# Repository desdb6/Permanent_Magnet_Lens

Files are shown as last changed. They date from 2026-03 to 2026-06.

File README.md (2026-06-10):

# Permanent Magnet Electron Lens
**A compact and open-source permanent magnet electron lens: from simulation to realisation**

*Bachelor's thesis — Des De Borger, supervised by Prof. Dr. Johan Verbeeck*  
*EMAT, Department of Physics, University of Antwerp, 2025–2026*

---

## Overview

This repository contains the simulation toolbox and CAD files developed for the design, optimisation, and experimental validation of a miniature electron lens based on a permanent Nd₂Fe₁₄B ring magnet with two ferromagnetic AISI 1018 pole pieces. The lens was tested in a 30 kV Tescan MIRA scanning electron microscope, producing magnified images with a magnification of ×6.

The goal is to contribute to the development of compact, energy-efficient, and open-source electron microscopes with a significantly lower cost threshold than conventional solenoid-based systems.

---

## Repository structure

```
├── sim.py                   # Full simulation toolbox (Lens class + helper functions)
├── NdFeB_BH_curve.csv       # BH-curve data for grade N35 Nd₂Fe₁₄B magnet
├── 3D_Models/
│   ├── polepiece.FCStd      # FreeCAD parametric model of the pole pieces
│   ├── polepiece.step       # STEP file for CNC manufacturing
│   ├── lens_holder.blend    # Blender model of the 3D-printed lens holder
│   ├── grid_holder.blend    # Blender model of the 3D-printed grid holder
│   └── aperture.blend       # Blender model of the 3D-printed aperture
└── README.md
```

---

## Physics background

The lens consists of a homogeneously magnetised Nd₂Fe₁₄B ring magnet combined with two axially symmetric pole pieces. The pole pieces concentrate the magnetic field into the air gap at the centre of the lens, producing a strongly peaked, cylindrically symmetric field B(z) along the optical axis.

The field is modelled analytically by treating the pole-piece surfaces bordering the air gap as homogeneously charged magnetic surface charge distributions (annuli with charge density ±σ_M). The on-axis field is:

$$B(z) = \frac{B_m A_m}{A_g} \cdot \frac{1}{2}\left[\left(z+\frac{d}{2}\right)\left(\frac{1}{\sqrt{(z+d/2)^2+R_1^2}}-\frac{1}{\sqrt{(z+d/2)^2+R_2^2}}\right) - \left(z-\frac{d}{2}\right)\left(\frac{1}{\sqrt{(z-d/2)^2+R_1^2}}-\frac{1}{\sqrt{(z-d/2)^2+R_2^2}}\right)\right]$$

where R₁ and R₂ are the inner and outer radii of the pole-piece surfaces, d is the air gap width, and the prefactor accounts for demagnetisation via the permeance coefficient P_ci.

Electron trajectories are computed by numerically solving the relativistically corrected paraxial ray equation:

$$\frac{d^2r}{dz^2} + \frac{\eta^2 B(z)^2}{4V} r = 0, \quad V = \Phi\left(1 + \frac{e}{2m_e c^2}\Phi\right)$$

using an 8th-order Runge-Kutta method (`DOP853` via `scipy.integrate.solve_ivp`).

---

## Installation

```bash
git clone https://github.com/desdb6/Permanent_Magnet_Lens.git
cd Permanent_Magnet_Lens
pip install numpy scipy matplotlib
```

**Requirements:** Python 3.9+, NumPy, SciPy, Matplotlib

The BH-curve file `NdFeB_BH_curve.csv` must be present in the working directory for the `Lens` class to function.

---

## Quick start

```python
from sim import Lens, Mesh

# Define lens geometry (all lengths in mm, field in T, voltage in V)
lens = Lens(
    R_1=0.8,                    # Inner radius of pole-piece surface (mm)
    R_2=3.25,                   # Outer radius of pole-piece surface (mm)
    R_1_magnet=4.5,             # Inner radius of ring magnet (mm)
    R_2_magnet=6.0,             # Outer radius of ring magnet (mm)
    d=0.8,                      # Air gap width (mm)
    d_magnet=2.0,               # Magnet thickness (mm)
    B_r_magnet=1.17,            # Effective remanent field (T)
    B_r_magnet_theoretical=1.17,# Theoretical remanent field for BH-curve scaling (T)
    T=30e3,                     # Accelerating voltage (V)
    setup_length=228,           # Total column length (mm)
    lens_position=114,          # Lens position along column (mm)
    n=10000                     # Number of evaluation points
)

# Compute and display lens properties
lens.update_B_r_yoke()          # Compute effective field accounting for demagnetisation
lens.update_T()                 # Apply relativistic correction
lens.calculate_B_field()        # Compute B(z) along the optical axis
lens.calculate_lens_properties()# Compute f, Z_Fi, Z_Pi via ray tracing
lens.calculate_aberration_coeff()
lens.display_properties()       # Print results and plot ray diagram
```

**Output:**
```
Maximum flux density = 1.120 T
Pci = 2.575
Z_Fi = 11.377 mm
Z_Pi = -0.060 mm
f    = 11.437 mm
D    = 1.22 mm^-2
```

---

## Key features

### Interactive B-field explorer
Adjust all lens parameters with sliders and see B(z) update in real time. Press Enter to proceed to lens simulation with the selected parameters.

```python
from sim import make_lens_interactive
make_lens_interactive()
```

### Parameter variation plots
Plot how lens properties (f, Z_Fi, Z_Pi, P_ci, B_max) vary as a function of each geometry parameter individually.

```python
lens.variable_R_1(R_1_min=0.3, R_1_max=3.0, R_1_n=50)
lens.variable_R_2(R_2_min=1.0, R_2_max=6.0, R_2_n=50)
lens.variable_d(d_min=0.3, d_max=3.0, d_n=50)
lens.variable_B_r(B_r_min=0.8, B_r_max=1.4, B_r_n=50)
lens.variable_T(T_min=20, T_max=40, T_n=50)   # voltage in kV
```

Distortion coefficient variants are also available:
```python
lens.variable_R_1_ab(0.3, 3.0, 50)
lens.variable_R_2_ab(1.0, 6.0, 50)
lens.variable_d_ab(0.3, 3.0, 50)
lens.variable_B_r_ab(0.8, 1.4, 50)
```

### Ray tracing and image formation
```python
# Set up object position and height
lens.setup_parameters(object_pos=94, object_height=1.5, lens_pos=101.08)

# Plot ray diagram with custom initial conditions
import numpy as np
initial_values = np.array([[1, 0], [0, 0.01], [-1, 0]])
lens.plot_setup(initial_values=initial_values)
```

### Monte Carlo shadowgraph simulation
Simulate the rear mesh shadowgraph experiment used to measure the focal length experimentally. Runs continuously until interrupted with Ctrl+C.

```python
mesh = Mesh(pos=144.22, line_dist=254e-3, line_thickness=50e-3)
lens.add_mesh(mesh)

lens.monte_carlo(
    object_height=0,
    opening_angle=100e-3,
    pixel_size=55e-3,       # AdvaPIX/MiniPIX pixel size (mm)
    camera_pos=228,
    pixel_count=256,
    voxel_length=0.05
)
```

### BH-curve and operating point
```python
from sim import BH_curve_magnet, plot_operating_point

spline = BH_curve_magnet(B_max=1.17)  # Scale BH-curve to target B_r
plot_operating_point(spline, reluctance_correction=0.39)
```

---

## Optimal lens parameters and results

| Parameter | Symbol | Value |
|---|---|---|
| Inner pole-piece radius | R₁ | 0.8 mm |
| Outer pole-piece radius | R₂ | 3.25 mm |
| Air gap width | d_g | 0.8 mm |
| Magnet inner radius | R₁_m | 4.5 mm |
| Magnet outer radius | R₂_m | 6.0 mm |
| Magnet thickness | d_m | 2.0 mm |
| Remanent field (N35 grade) | B_r | 1.17 T |

| Simulated property | Value |
|---|---|
| Focal length f_sim | 11.437 mm |
| Image principal plane z_Pi | −0.060 mm |
| Permeance coefficient P_ci | 2.575 |
| Maximum flux density B_max | 1.120 T |
| Distortion coefficient D | 1.22 mm⁻² |

**Experimentally measured focal length (30 kV, Tescan MIRA SEM):**  
f_exp = 25 ± 2 mm

The discrepancy is attributed to magnetic flux leakage. A numerical validation shows that scaling the field by a factor of 0.67 reproduces the experimental focal length, giving a corrected simulation of f = 24.6 mm.

---

## CAD files and manufacturing

The pole pieces were manufactured from AISI 1018 steel (surface passivated) by [Protolabs Network](https://www.hubs.com) using CNC machining. The STEP file can be uploaded directly to any CNC on-demand service.

The lens holder, grid holder, and aperture were 3D-printed in conductive PLA (resistivity ~450–6000 kΩ measured) to prevent charge buildup inside the electron microscope column. Blender source files are included.

---

## Notes

- All lengths are in **millimetres** throughout the codebase
- `B_r_magnet` scales the BH-curve so that B(H=0) equals the supplied value; it does not assume a fixed linear permeability
- The `leak_factor` parameter in the `__main__` block can be used to model flux leakage (e.g. `leak_factor=0.67` to match the experimental result)
- `NdFeB_BH_curve.csv` must use semicolons as delimiters and commas as decimal separators (European format), as exported from the original data source

---

## License

MIT License — free to use, modify, and distribute with attribution.

---

## Contact

Des De Borger — [Des.deborger@student.uantwerpen.be](mailto:Des.deborger@student.uantwerpen.be)

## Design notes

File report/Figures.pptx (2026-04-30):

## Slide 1

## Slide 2

Detector

Mesh grating

Lens

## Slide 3

Detector

Mesh grating

Lens

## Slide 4

Detector

Mesh grating

Lens

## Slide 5

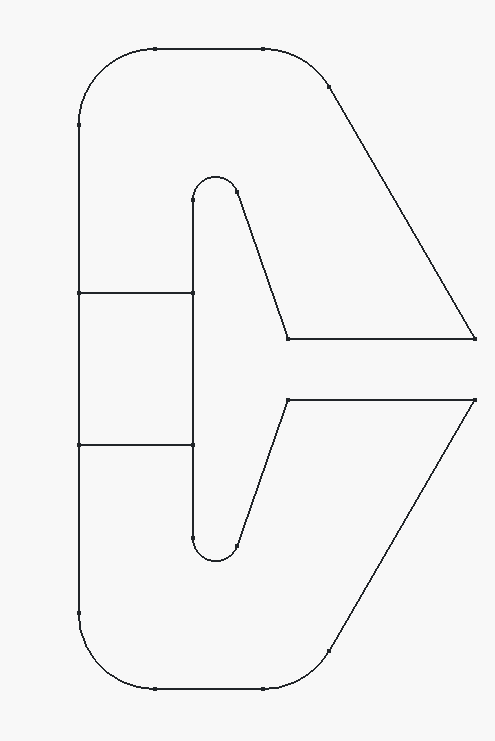
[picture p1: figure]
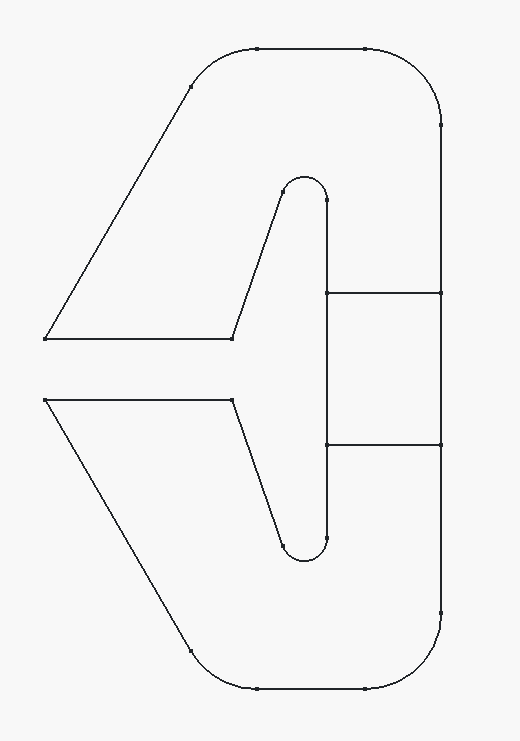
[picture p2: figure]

Poolschoen

Luchtspleet

Magneet

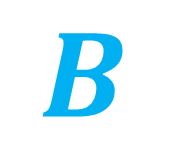
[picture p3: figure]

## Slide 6

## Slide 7

Polepiece

Nd-magneet

Gap (lucht)

Polepiece

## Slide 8

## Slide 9

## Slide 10

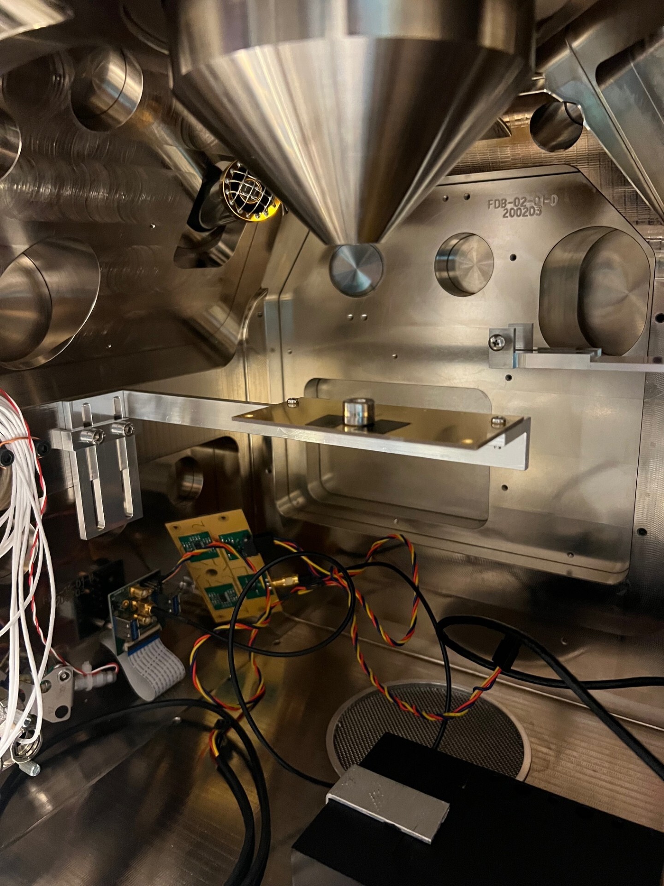
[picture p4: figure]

Elektronenbron

Lensplatform

Elektronendetector

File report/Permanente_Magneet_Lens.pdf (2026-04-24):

2025 - 2026

Simulatie, | realisatie | en | karakterisatie

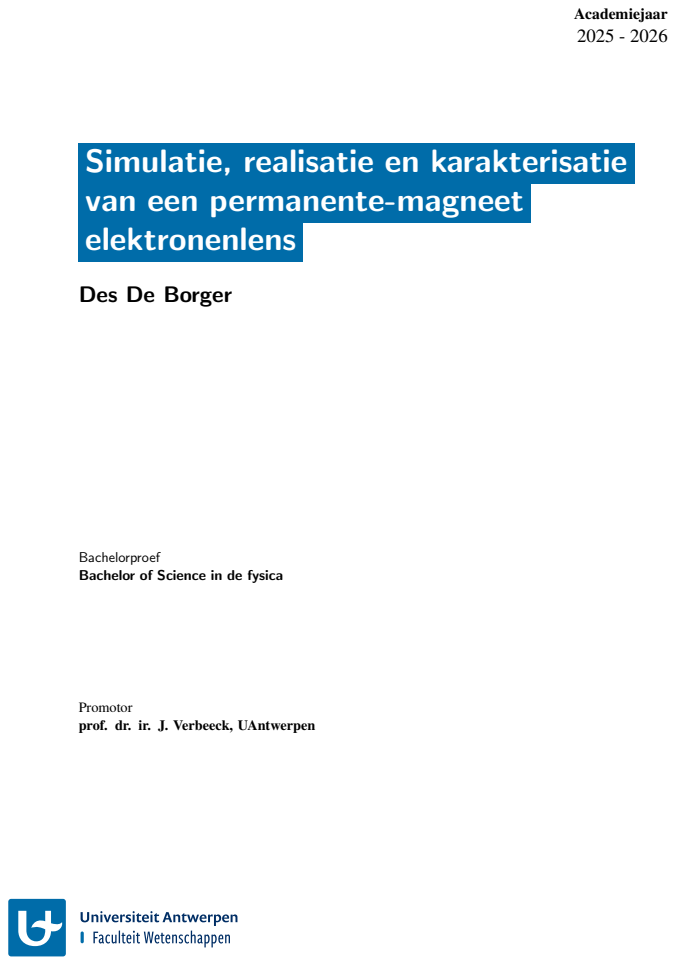
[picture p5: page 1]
Academiejaar; elektronenlens

van | een | permanente-magneet

Des De Borger

Bachelorproef
Bachelor of Science in de fysica

Promotor
prof. dr. ir. J. Verbeeck, UAntwerpen

Disclaimer Bachelorproef

Dit document is een examendocument dat niet werd gecorrigeerd voor eventueel vastgestelde fouten. Zonder voorafgaande schriftelijke toestemming van zowel de promotor(en) als de auteur(s) is overnemen, kopieren, gebruiken of realiseren van deze uitgave of gedeelten ervan verboden. Voor aanvragen ¨ tot of informatie i.v.m. het overnemen en/of gebruik en/of realisatie van gedeelten uit deze publicatie, wendt u tot de universiteit waaraan de auteur is ingeschreven.

Voorafgaande schriftelijke toestemming van de promotor(en) is eveneens vereist voor het aanwenden van de in dit afstudeerwerk beschreven (originele) methoden, producten, schakelingen en programma’s voor industrieel of commercieel nut en voor de inzending van deze publicatie ter deelname aan wetenschappelijke prijzen of wedstrijden.

Dit document is in overeenstemming met het masterproefreglement en de gedragscode en nagekeken door promotor en begeleider.

# Inhoudsopgave

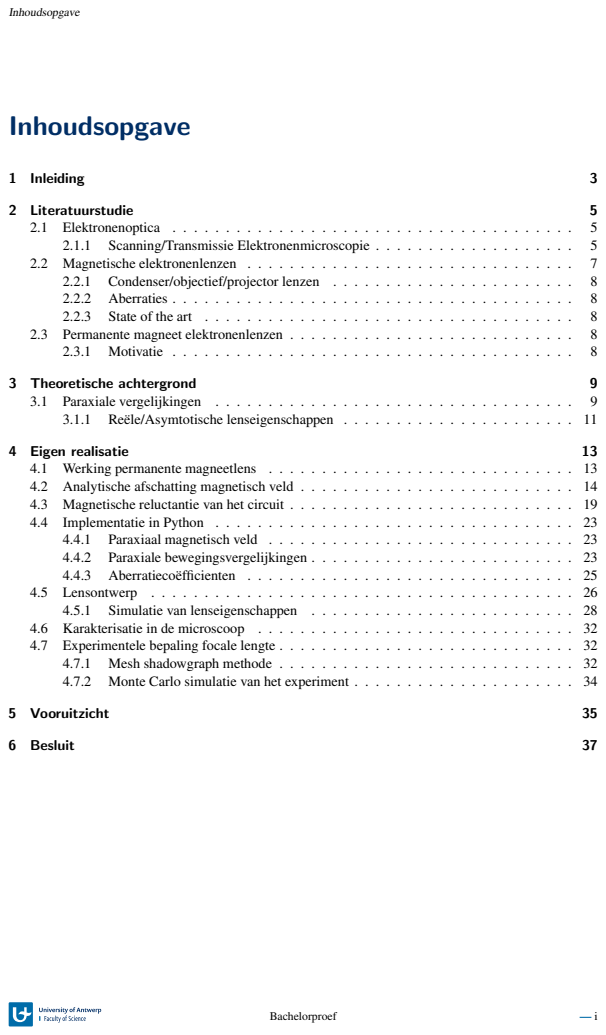
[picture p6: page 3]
Inhoudsopgave; 1 Inleiding; 2 Literatuurstudie; 3 Theoretische achtergrond; 4 Eigen realisatie; 5 Vooruitzicht; 6 Besluit; Bachelorproef

## Samenvatting

## Simulatie, realisatie en karakterisatie van een permanente-magneet elektronenlens

Des De Borger

Oude samenvatting, nog up te daten Elektronenmicroscopie is een uiterst belangrijke beeldvormingstechniek waarmee men voorwerpen met afmetingen in het nanometergebied kan bestuderen. Bij een Transmissie Elektronenmicroscopie (TEM) wordt een elektronentransparant preparaat bestraald met elektronen, waarna het resulterende beeld uitvergroot en op een detector gefocust moet worden. Het elektronenoptisch systeem van een elektronenmicroscoop bestaat typisch uit een objectief- en een projectorlens, aangevuld met verschillende aberratiecorrectoren en aperturen.

Een magnetische lens bestaat typisch uit een solenoïde die een axissymetrisch magnetisch veld opwekt. Twee polepieces met een hoge permeabiliteit zullen dit veld dan beïnvloeden zodat we op de as van de optische opstelling de gewenste vorm van het magneetveld krijgen. Wanneer elektronen doorheen de opstelling bewegen wordt hun beweging door de Lorentzkracht van het magnetisch veld, waardoor we het beeld kunnen focussen, vergroten of verkleinen.

Dit soort lenzen hebben enkele nadelen, met name dat ze redelijk groot zijn, de productie ervan duur is, en dat er een zeer precieze constante stroom nodig is om het magnetisch veld in stand te houden. In deze bachelorproef onderzoeken we de viabiliteit van een miniatuurlens op basis van een permanente NdFeB-magneet, welke zowel kleiner, goedkoper als toegankelijker in gebruik zou zijn. De lens bestaat uit een kleine (12mm buitendiameter) ringmagneet en twee symmetrische polepieces uit ASI1018 staal.

Eerst berekenen we d.m.v. een analytische uitdrukking en een numerieke simulatie in het simulatieprogramma SIMION hoe het magnetisch veld er in functie van de vorm van de polepieces uit ziet. Vervolgens kunnen we de baan van de elektronen doorheen de lens met Python simuleren om de lenseigenschappen te berekenen (focaalafstand, object principal plane, image principal plane). Hierbij is het uiterst belangrijk om rekening te houden met eventuele magnetische saturatie van de polepieces. We trachtten een dunne lens te ontwerpen met een focaalafstand van ∼ 11.5mm.

Eens we een ontwerp hebben vastgelegd kunnen we m.b.v. een CNC service de lens realiseren. De lenseigenschappen worden gekarakteriseerd in een 30keV SEM waarvan het optisch systeem sterk lijkt op een de werking van een TEM. We willen hierbij nagaan hoe de werkelijke lenseigenschappen en het magnetisch veld van de voorspelde grootheden afwijken, en wat de mogelijke storingen zouden kunnen zijn. Daarnaast willen we ook onderzoeken welke aberraties in welke mate aanwezig zijn. Op deze manier krijgen we meer inzicht in het ontwerp en de werking van permanente-magneet elektronenlenzen.

# 1 Inleiding

Elektronenmicroscopie is een uiterst krachtige techniek die wordt gebruikt om objecten op nanometerschaal in beeld te brengen [23]. De grote magnificaties die met elektronenmicroscopen bereikbaar zijn maakt het een zeer belangrijk hulpmiddel met toepassingen in uiteenlopende gebieden zoals halfgeleiderfysica, geneeskunde, forensische onderzoeken enzovoorts. De discipline van de elektronenmicroscopie is ontwikkeld na het besef dat het oplossend vermogen van een lichtmicroscoop fundamenteel is gelimiteerd door de golflengte van zichtbaar licht, wat ontdekt werd door Ernst Karl Abbe in 1873. Een oplossing voor dit probleem werd aangeboden door Louis de Broglie in 1924 met zijn theorie van elektronengolven [9], waarvan de golflengte omgekeerd evenredig is met het impuls p van het elektron, wat toeliet om met elektronen een groter oplossend vermogen te verkrijgen. In 1926 toonde Hans Busch aan dat het mogelijk is om met een cilindrische magnetische lens een elektronenbundel te deflecteren en te focusseren, wat nieuwe mogelijkheden bood voor het ontwikkelen van elektronenlenzen [7].

Doorheen de jaren heeft de theorie van elektronenoptica zich verder ontwikkeld en zijn
elektronenmicroscopen door nieuwe inzichten en vooruitgang in productiemogelijkheden enkel beter geworden. Met High Resolution Transmissie Elektronenmicroscopie (HRTEM) is het mogelijk om resoluties van de orde van ∼ 50pm te bereiken. Een krachtige elektronenmicroscoop bestaat intussen typisch uit meer dan 7 lenzen, aangevuld door aberratiecorrectoren of specifieke specimenhouders om in-situ experimenten mogelijk te maken [22].

Klassiek gebruikte magnetische elektronenlenzen bestaan uit een solenoïde om een magnetisch veld te maken dat de elektronen doet deflecteren d.m.v. de Lorentzkracht [19]. Om een voldoende groot magnetisch veld (∼ 2 − 3T) te kunnen induceren hebben dit soort lenzen en correctoren een of meerdere geleidende spoelen met een kleine weerstand nodig. Dit maakt dat de spoel een groot aantal windingen moet hebben, wat een grote hoeveelheid koperdraad vereist. Hierdoor zijn magnetische solenoïdelenzen typisch groot, zwaar en kostelijk.

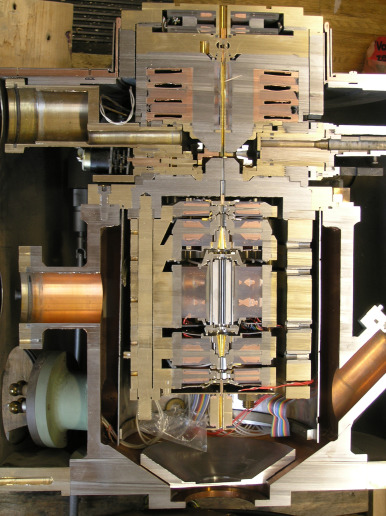
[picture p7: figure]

Figuur 1.1: Doorsnede van een Darmstadt aberratiecorrector. In een typische elektronenlens maakt men gebruik van spoelen om een magnetisch veld op te wekken. [12]

Mede om deze redenen blijkt de ontwikkeling van een open-source elektronenmicroscoop een traag en moeizaam proces. Wanneer men een toegankelijke, kleinere elektronenmicroscoop ontwerpt (zoals het open source NanoMi project), kiest men er vaak voor om een elektrostatische Einzellens te gebruiken [17]. Dit brengt enkele nadelen met zich mee, voorlamelijk dat er een relatief grote voeding nodig is om

Bachelorproef | — 3

HOOFDSTUK 1. INLEIDING

een voldoende grote spanning op te wekken die de elektronen genoeg kan deflecteren. Een andere optie is het gebruik van permanente magneet elektronenlenzen: met behulp van kleine NdFeB magneten en ferromagnetische polepieces is het mogelijk om een magnetisch veld te maken dat een elektronenbundel kan focusseren.

Onderzoeksvraag

In deze thesis onderzoeken we de viabiliteit van een elektronenlens gebaseerd op een ringvormige NdFeB magneet met twee symmetrische polepieces die worden geproduceerd door een CNC-service. Hierbij zullen we een model van de lens moeten opstellen om het magnetisch veld af te schatten, het gedrag van de lens in Python simuleren om de de lenseigenschappen te bepalen, en de lens karakteriseren in een elektronenmicroscoop met een versnelspanning van 30KeV. Hierbij zullen we analyseren hoe de experimenteel bepaalde lenseigenschappen zoals de focale lengte afwijken van de gesimuleerde waarden, en welke aberraties de lens vertoont. Onze onderzoeksvraag luidt daarom as volgt:

In hoeverre is het mogelijk om een miniatuur-elektronenlens bestaande op een ringvormige NdFeB en ferromagnetische polepieces te ontwerpen en gebruiken in een elektronenmicroscoop met een versnelspanning van 30KeV?

Hoofdstuk 2 geeft een overzicht van enkele begrippen en principes die belangrijk zijn bij het ontwerpen van een elektronenlens, en beargumenteren we welke voordelen een permanente magneet elektronenlens heeft t.o.v. de klassiek gebruikte lenzen. Hoofdstuk 3 geeft een afleiding van de paraxiale bewegingsvergelijkingen, die we nodig zullen hebben om de lenseigenschappen te simuleren eens we het magnetisch veld van de lens kennen. Hoofdstuk 4 gaat dieper in op de eigen implementatie van deze thesis. Hierbij geven we een beschrijving van hoe de lens werkt, maken we een analytische afschatting van het magnetisch veld in de lens, implementeren we een klasse in Python om de lenseigenschappen te voorspellen, en geven we een beschrijving van de experimentele resultaten wanneer we de lens in de microscoop hebben getest. In hoofdstuk 5 bespreken we hoe het ontwerp verbeterd kan worden en hoe dit onderzoek kan bijdragen aan het ontwikkelen van een toegankelijkere open-source elektronenmicroscoop. Hoofdstuk 6 geeft nog enkele laatste opmerkingen en een conclusie van dit onderzoek.

4 — | Bachelorproef

# 2 Literatuurstudie

### 2.1 Elektronenoptica

In elektronenoptica maakt men gebruik van elektronen in plaats van fotonen om beelden te vormen. Dit laat ons toe om een grotere resolutie te krijgen dan met optische microscopen, aangezien het oplossend vermogen van een microscoop gelimiteerd wordt door de golflengte van de golven die de beelden vormen. De afmetingen van de kleinste details dmin die kunnen worden waargenomen met een golflengte λ is [13]:

dmin =

kλ
A

(2.1)

Hierbij is k een constante tussen 0.6−0.8 en A is de numerieke apertuur van de lens. Door dit verband is de golflengte de beperkende factor voor de magnificatie van een optische microscoop. Met een elektronenmicroscoop is het daardoor niet mogelijk om voorwerpen kleiner dan ∼ 125nm in beeld te brengen. Voor elektronen wordt de golflengte echter gegeven door:

λ =

h
p

=

h
√
2meE

(2.2)

Als we de elektronen vanuit rust versnellen met een versnelspanning Φ, dan krijgen we:

λ =

h
√
2meeΦ

(2.3)

Op deze manier kunnen we dus de golflengte verkleinen door een grotere versnelspanning te gebruiken. Bij HRTEM gebruikt men typisch versnelspanningen tot 300KeV, waarmee picometer resoluties bereikt kunnen worden. Het huidige record voor beste resolutie staat op 0.5A˚, wat bereikt werd m.b.v. elektronen pytografie [15]. Elektronenoptica is op deze manier een enorm grote verbetering op ’gewone’ optica. De instrumenten die nodig zijn om aan elektronenoptica te doen (zoals elektronenlenzen), zijn echter veel complexer dan hun tegenhangers die met lichtgolven beelden vormen. Een elektronenmicroscoop bestaat minstens uit een elektronengun, een of meerdere elektromagnetische lenzen met aberratiecorrectoren, eventueel een of meerdere aperturen, en een elektronendetector. Op deze manier kunnen we op dezelfde manier als met licht een voorwerp bestralen met elektronen, zodanig dat de lenzen een uitvergroot beeld van dat voorwerp op de detector zullen afbeelden.

### 2.1.1 Scanning/Transmissie Elektronenmicroscopie

De twee belangrijkste vormen van elektronenmicroscopie zijn Scanning Elektronenmicroscopie (SEM) en Transmissie Elektronenmicroscopie (TEM). De beeldvorming gebeurt bij beide technieken op een andere manier, en de opstellingen in de microscoop zijn daardoor ook anders. In deze sectie geven we een korte beschrijving van deze twee technieken.

In een SEM zal men een elektronenbundel m.b.v. elektronenlenzen in een zeer smalle spot gaan focusseren (∼ 3nm), welke dan over het sample gescand wordt. Deze elektronenbundel zal dan secundaire elektronen uit het oppervlak van het sample losslaan. De richting waarin deze secundaire elektronen loskomen, wordt beïnvloed door het oppervlak aan het punt waar ze loskomen en bevatten zo dus informatie over het oppervlak. Een elektronendetector die zich ergens boven het sample bevindt zal de secundaire elektronen dan verzamelen. Door de elektronenbundel met scanning coils over het oppervlak

HOOFDSTUK 2. LITERATUURSTUDIE

te scannen, kunnen we voor elk punt op het oppervlak meten hoeveel elektronen er in de richting van de detector vrijkomen en op deze manier een beeld van het oppervlak vormen. De maximale versnelspanning van een SEM ligt typisch tussen 0−30KeV [13] omdat een grotere energie te veel schade aan het sample kan opbrengen. Figuur 2.1a toont een illustratie van het werkingsprincipe van een SEM en Figuur 2.1b toont een SEM beeld van rode bloedcellen.

(a) Werkingsprincipe van een SEM waarbij de elektronenbundel over het sample wordt gescand en er secundaire elektronen los worden geslagen. [22]

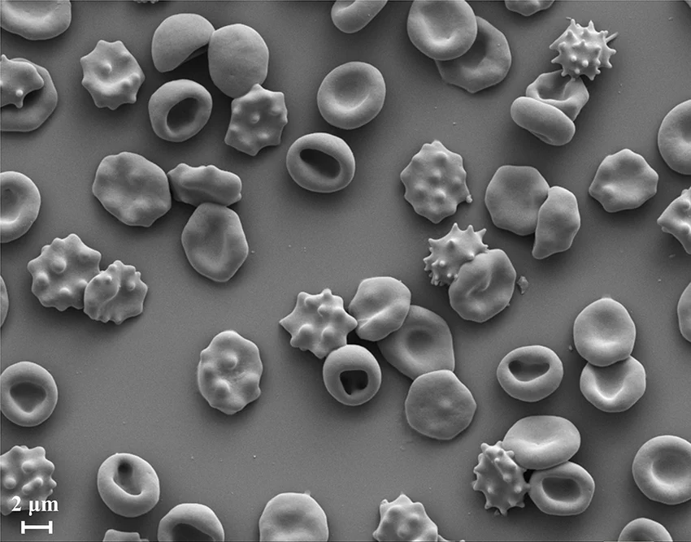
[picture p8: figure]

(b) Beeld van rode bloedcellen opgenomen met een SEM. [10]

Figuur 2.1

(a) Werkingsprincipe van een TEM waarbij een brede elektronenbundel heel het sample belicht en heel het beeld in 1 keer wordt opgenomen met een detector onder het sample. [22]

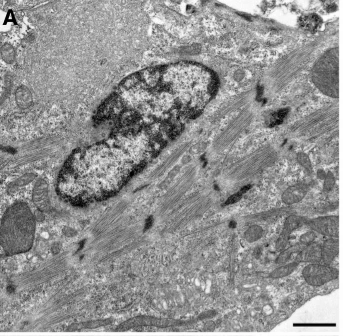
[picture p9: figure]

(b) Beeld van celorganellen opgenomen met een TEM. [24]

Figuur 2.2

In een TEM gaat men niet scannen over het oppervlak, maar belichten we een uiterst dun en elektronentransparant specimen met een brede bundel elektronen, welke in het indeale geval een perfecte vlakke golf voorstellen. De elektronen zullen dan interageren met het specimen, en op sommige plaatsen meer of minder geabsorbeerd of gescattered worden. De uitgaande elektronenbundel bevat dan opnieuw in-

6 — | Bachelorproef

2.2. MAGNETISCHE ELEKTRONENLENZEN

formatie over het specimen. Door gebruik te maken van een of meerdere elektronenlenzen kunnen we dan een uitvergroot beeld van het sample afbeelden op een elektronendetector die zich onder het sample bevindt. De detector is in dit geval bijvoorbeeld een fluorescerend scherm, waarop heel het beeld in een keer afgebeeld wordt (in tegenstelling tot een SEM). De versnelspanning in een TEM kan tot 300KeV bedragen, waardoor het oplossend vermogen beter is dan dat van een SEM. Figuur 2.2a toont een illustratie van het werkingsprincipe van een TEM en Figuur 2.2b toont een TEM beeld van celorganellen.

### 2.2 Magnetische elektronenlenzen

Om met elektronen beelden te kunnen vormen zijn elektronenlenzen een cruciale component van de optishe opstelling. Er zijn twee manieren om een elektronenbundel te doen deflecteren: met de elektrisch veld via de Coulombkracht, en met een magnetisch veld via de Lorentzkracht. Er bestaan zowel elektrostatische als magnetische lenzen. Het gebruik van magnetische elektronenlenzen is echter veel prominenter dan elektrostatische elektronenlenzen, aangezien de grootte van de elektrische velden bij TEM versnelspanningen praktisch niet haalbaar zijn en te grote veiligheidsgevaren veroorzaken. Boven-
dien zal een elektrostatische lens de energieen van de elektronen in de elektronenbundel be ¨ | ïnvloeden.
Dit kan een spreiding van de energieen veroorzaken, wat aanleiding geeft tot chromatische aberratie (zie ¨ verder). [11]

Figuur 2.3: Illustratie van een magnetische solenoïdelens. Dit soort lens maakt een magnetisch veld dat symmetrisch is rond de optisceh as van het systeem. Door een bundel elektronen door de lens te sturen ondervinden deze zowel een azimutale als een radiale Lorentzkracht. Deze laatste kan gebruikt worden om de elektronen te focusseren. [22]

Met een magnetische elektronenlens maakt men typisch een axissymetrisch magnetisch veld rond de optische as, waarvan de sterkte langs de optische as varieert. Vanwege de symmetrie is azimutale com- ¨ ponent van het magnetisch veld gelijk aan nul. Dit soort veld worden opgewekt met een solenoïde waar een stroom doorheen gestuurd wordt, wat men een solenoïdelens noemt. Door een elektronenbundel door de solenoïde te sturen zullen de elektronen die zich niet op de optische as bevinden een Lorentzkracht ondergaan en afbuigen. De elektronen ondergaan zowel een radiale kracht, waarmee de bundel gefocusseerd kan worden, als een azimutale kracht, die voor een precessie van de elektronenbundel rond de optische as zorgt. In hoofdstuk 3 gaan we dieper in op de bewegingsvergelijkingen die het afbuigen van de elektronen beschrijft. Figuur 2.3 toont een illustratie van de manier waarop elektronen door een solenoïdelens zullen bewegen.

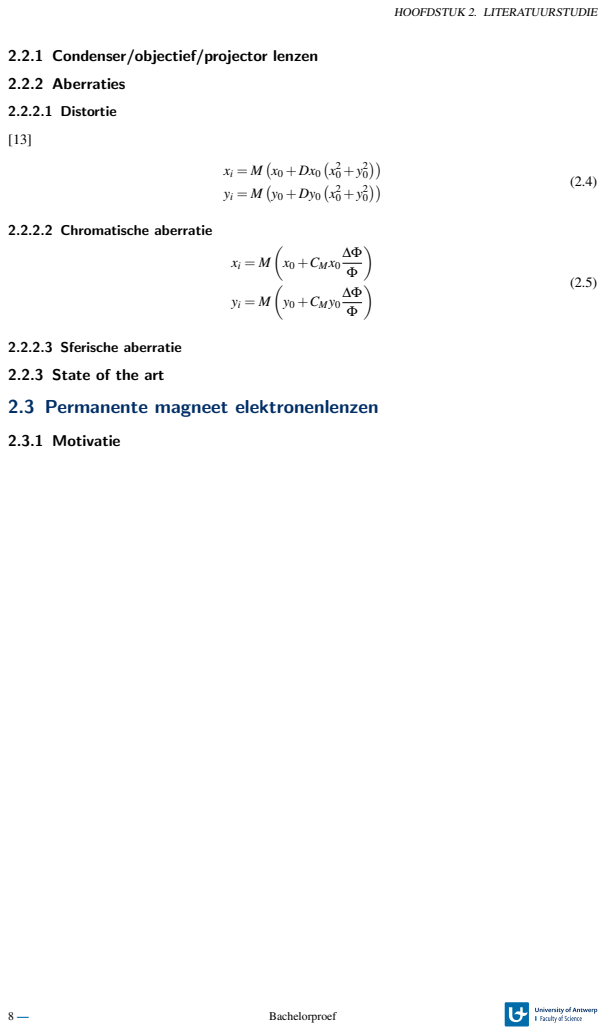
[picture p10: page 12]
HOOFDSTUK 2. LITERATUURSTUDIE; 2.2.2 Aberraties; 2.2.2.1 Distortie; 2.2.2.2 Chromatische aberratie;  x0 +CMx0;  y0 +CMy0; 2.2.2.3 Sferische aberratie; 2.3.1 Motivatie; Bachelorproef

2.2.1 Condenser/objectief/projector lenzen

2.2.3 State of the art
2.3 Permanente magneet elektronenlenzen

# 3 Theoretische achtergrond

Naar de appendices?

### 3.1 Paraxiale vergelijkingen

In deze sectie geven we een verkorte afleiding van de paraxiale vergelijking die de baan van een elektronenbundel in een axissymetrisch magnetisch veld beschrijft. De afleiding is gebaseerd op [13]. De meest algemene bewegingsvergelijking van een elektron in een elektromagnetisch veld wordt gegeven door de tweede wet van Newton waarbij de Lorentzkracht op het elektron inwerkt:

m

d

2
r
dt²
= −e(E+v×B) | (3.1)

In ons geval beschouwen we een magnetische lens, dus stellen we het elektrostatisch veld E = 0. Verder veronderstellen we dat het veld axissymetrisch is, dus is het natuurlijk om deze vergelijking in cilin-
dercoordinaten ¨ | (r,θ,z) te beschrijven. Uit de symmetrie van het systeem volgt dat de angulaire compo-
nent van het magnetisch veld nul moet zijn, m.a.w. B = (Br

,0,Bz). Vergelijking 3.1 componentsgewijs uitrekenen geeft dan:

er : m

d

2
r
dt²

−r

dθ

dt 2

!
= −erBz

dθ
dt

(3.2)

eθ : m

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
= −e
Br

dz
dt

−Bz

dr

dt
(3.3)

ez : m

d

2
z
dt²

= eBr

dθ
dt

(3.4)

In het linkerlid van vergelijking 3.3 herkennen we de Leibnizregel en kan herschreven worden als:

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
(3.5)

We beschouwen nu enkel paraxiale elektronen, m.a.w. elektronen die zich dicht bij de optische as van het systeem (r = 0) bevinden. We kunnen aantonen dat Bz(r,z) ontwikkeld kan worden in een reeks van machten in r. Stellen we B(z) = Bz(r = 0,z):

Bz(r,z) = B(z)−

r

2
4

d

2B(z)
dz²

+

r

4
64

d

4B(z)
dz⁴

+O(r

6
) | (3.6)

Voor kleine r maken we de benadering dat Bz(r,z) = B(z). Nu leiden we een relatie tussen B en Br af. We beschouwen een cilindrisch volume rond de z-as van het systeem zoals op Figuur 3.1 en gebruiken de tweede Maxwellvergelijking in integraalvorm, welke ons vertelt dat de totale flux doorheen een gesloten ondervlak gelijk moet zijn aan 0.

HOOFDSTUK 3. THEORETISCHE ACHTERGROND

Figuur 3.1: We kunnen de tweede Maxwell gebruiken om een relatie te vinden tussen Br en B(z) op de symmetrie-as van het systeem. We tekenen daarvoor een cilindervormig Gauss-oppervlak waardoor de totale flux R
B· dS moet verdwijnen.

De flux doorheen de mantel wordt gegeven door 2πrδzBr , terwijl de flux doorheen het boven-en ondervlak gegeven wordt door πr

2
(B(z+δz)−B(z) ≈ πr

2 dB
dz . Hieruit volgt:
Z

S

B· dS = πr

2

dB
dz

+2πrδzBr = 0 ⇔ Br = −

1
2

r

dB
dz

(3.7)

Invullen van 3.7 in 3.5 geeft:

d

dt
mr²

dθ

dt

= er
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
er²B

(3.8)

Beide leden integreren¹
en vereenvoudigen geeft:

dθ
dt

=

eB
2m

= η

2B | (3.9)

met η =

p e
2m ≈ 3×10⁵

q Q
kg voor elektronen. We kunnen nu vergelijking 3.9 invullen in vergelijking 3.2:
d

2
r
dt²

= −r

e

2B(z)

2
2m²

+r

e

2B(z)

2
4m²

= −η

4B(z)

2
r | (3.10)

Nu willen we nog de variabele t vervangen door z om zo een gewone differentiaalvergelijking in 1 variabele te krijgen. Stel dat we werken met een versnelspanning Φ, dan geldt er wegens behoud van energie dat:
1
2

m

dz

dt 2
= eΦ ⇔

dz
dt

=

r
2eΦ
m

= 2η

√
Φ | (3.11)

Waaruit volgt:
d

2
dt²

= 4η

2Φ

d

2 dz² | (3.12)

Door dit in te vullen in 3.10 komen we uiteindelijk bij de paraxiale bewegingsvergelijking voor axissymetrisch magnetisch veld:
d

2
r
dz²

+

η

2B(z)

2
4Φ
r = 0 | (3.13)

De relativistisch correcte versie van deze vergelijking is:

d

2
r
dz²

+

η

2B(z)

2
4V
r = 0 | (3.14)

Met V = Φ

1+

e
2mc² Φ
. Deze vergelijking zullen we later numeriek oplossen voor het geschatte magnetisch veld om de lenseigenschappen van lenzen te simuleren.

1

In principe moet hier nog een constante +C bij, maar aangezien dθ
dt = 0 bij B = 0 is C = 0.
10 — | Bachelorproef

3.1. PARAXIALE VERGELIJKINGEN

Merk op dat de paraxiale bewegingsvergelijking lineair is. Dit betekent dat twee lineair onafhankelijke oplossingen voldoende is om de algemene oplossing van deze vergelijking op te stellen. Conventioneel noemt men z0 de positie van het vlak van het voorwerp dat we met een magnetische lens willen uitvergroten, en kiest met twee basisoplossingen g(z) en h(z) zodanig dat:

g(z0) = 1,g

′
(z0) = 0 | (3.15)

h(z0) = 0,h

′
(z0) = 1 | (3.16)

Merk op dat de oplossing g het gedrag van een parallelle bundel beschrijft. Immers, de oplossing voor de paraxiale bewegingsvergelijking van een parallel elektron dat initieel op een constante afstand r0 van de optische as beweegt kan geschreven worden als r0g(z). Stel dat g(z) een nulpunt heeft, dan kruisen alle initieel parallel bewegende elektronen de optische as in dat nulpunt. Dit is exact de gewenste werking van een magnetische elektronenlens; het nulpunt van g(z) is dan het brandpunt van de lens. Vergelijking 3.14 lijkt erg op een harmonische oscillator (met een frequentie afhankelijk van B

2
| ), wat betekent dat
de elektronen steeds naar de optische as worden afgebogen. In het algemeen zal g(z) daarom altijd een nulpunt hebben als B(z) ̸= 0.7

### 3.1.1 Reële/Asymtotische lenseigenschappen

Bij het berekenen van de lenseigenschappen is het belangrijk om een onderscheid te maken tussen de reele en asymptotische lenseigenschappen. Wanneer we meerdere lenzen in een opstelling gebruiken, ¨ zijn het namelijk de asymptotische lenseigenschappen die we nodig hebben om de afstanden tussen de lenzen en de vergroting te berekenen. Een voorbeeld wordt getoond op Figuur 3.2 waarbij we de reeele ¨ en asymptotische focale lengte vergelijken.

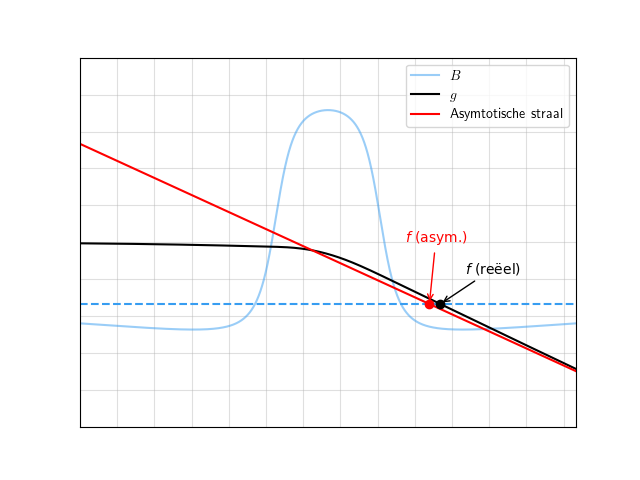
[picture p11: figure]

Figuur 3.2: Voorbeeld van het verschil tussen een reeele en een asomptotische lenseigenschap. In dit ¨
geval is de reeele focale lengte het punt waar de elektronenbaan ¨ | g de optische as kruist, en
de asymptotische focale lengte het punt waar de asymptoot rakend aan g voor z → ∞ de optische as kruist.

De focale lengte vinden we door te bepalen waar een parallel inkomende straal de otpische as van het systeem snijdt. In dit geval zijn er echter twee stralen die we kunnen bekijken, en dus ook twee focale lengtes te definieren: ¨

HOOFDSTUK 3. THEORETISCHE ACHTERGROND

- De reeele focale lengte is het punt waar een parallelle elektronenbundel op de optische as gefcous- ¨ seerd wordt. Dit is met andere woorden het nulpunt van g(z).
- De asymptotische focale lengte is het punt waar de asymptoot voor z → ∞ aan g de optiche as kruist. Als we een parallelle bundel op de lens insturen, lijkt het voor een observator die achter van het midden van de lens staat alsof de elektronen niet uit het reeel, maar het asymptotisch brandpunt ¨ komen. Ook wanneer we een beeld gaan vormen met een beeldafstand dir groot is vergeleken met f , moeten we de asymptotische focale lengte gebruiken om de vergroting te berekenen. De asymptotische focale lengte is daarom voor onze doeleinden de relevante waarde.

Extra sectie met uitleg waarom we best meer dan 1 lens nodig hebben om een diffractiepatroon uit te vergroten?
Meer uitleg over wat een hoofdvlak is?
12 — | Bachelorproef

# 4 Eigen realisatie

### 4.1 Werking permanente magneetlens

Voor we in de details van het ontwerpsproces van de lens duiken, is het verstandig om het concept van het ontwerp helder uit te leggen. Het doel is om een magnetisch veld te ontwerpen dat de elektronen op zo’n manier afbuigt zodanig dat een paralelle bundel geconcentreerd zal worden in een punt op de optische as. Hierbij willen we dat de lens aan enkele gewenste eigenschappen voldoet.

Ten eerste willen we een geschikte focale lengte zodat de lens bruikbaar is in een elektronenmicroscoop. Concreet zal deze lens getest worden in een Tescan MIRA SEM, waarin we een maximale totale afstand van 228.4mm van elektronenbron tot detector ter beschikking hebben. Om een bruikbare lens te maken is het daarom gewenst dat de focale lengte niet veel langer dan 10mm is. Verder zullen we werken we met een versnelspanning van 30KeV, wat een voorwaarde legt op de minimale sterkte van het magnetisch veld.

Ten tweede is het gewenst dat de lens die we maken, een dunne lens is. Meer concreet willen we dat de hoofdvlakken samenvallen in het midden van de lens. Op deze manier is het gemakkelijker om berekeningen te doen als we opstellingen met meerdere lenzen willen bouwen, aangezien de dunne lensformule dan toepasbaar is. Dit betekent dat we een sterk ruimtelijk geconcentreerd magnetisch veld in het midden van de lens willen; de elektronen interageren dan maar heel kort met het magnetisch veld, wat een dunne lenswerking geeft. Hoe geconcentreerder we het veld maken, hoe sterker het maximale veld moet zijn om dezelfde afbuiging te veroorzaken. Om een bruikbare lens te maken willen we op de optische as een magnetisch veld met een sterkte van ∼ 0.1−1T dat geconcentreerd is over een afstand van < 5mm.

Het ontwerp dat we in deze thesis onderzoeken en aan beide voorwaarden voldoet, wordt getoont op Figuur 4.1.

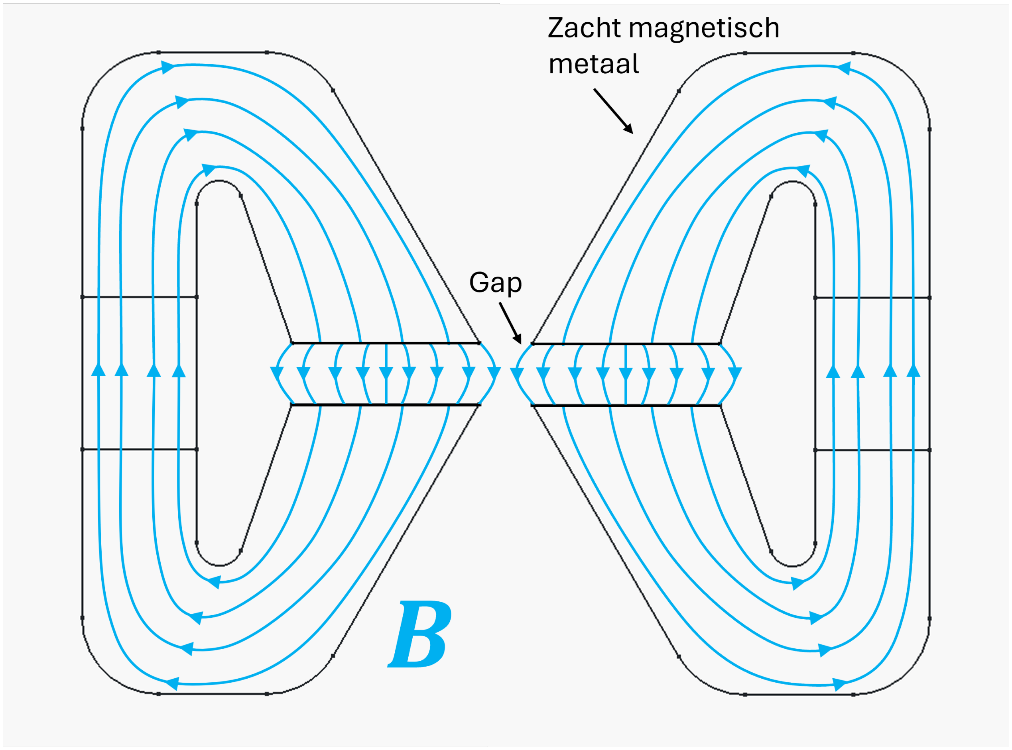
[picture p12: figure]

Figuur 4.1: Cross-sectie van het ontwerp van onze permanente magneetlens. Een homogeen gemagnetiseerde Nd-ringmagneet maakt een sterk magnetisch veld dat door twee zacht magnetische polepieces wordt geconcentreerd in het het gat van de lens.

HOOFDSTUK 4. EIGEN REALISATIE

Om een axissymetrisch veld te veroorzaken, maken we gebruik van een kleine ringvormige NdFeB magneet met een remanent magneetveld van ∼ 1.2T. We kunnen in principe enkel de magneet als lens gebruiken, maar dit is niet optimaal; het magnetisch veld zou dan te homogeen in de ruimte zijn, terwijl we een zo sterk mogelijk veld op de symmetrieas van de lens willen. We kunnen het veld naar het midden van de lens ’begeleiden’ d.m.v. polepieces gemaakt uit een zacht ferromagnetisch materiaal met een hoge permeabiliteit µ. Als de permabiliteit voldoende hoog is, dan zullen de grote meerderheid van de veldlijnen in de polepieces blijven en in het midden van de lens de opening of gap oversteken. Bij het oversteken van de opening tussen de polepieces lopen de velden niet perfect loodrecht van het ene oppervlak naar het andere, maar door randeffecten zullen ze naast de oppervlakken naar buiten buigen. Op deze manier krijgen we in het gat een lokaal sterk veld, zoals gewenst.

Voor de ringmagneet kiezen we een NdFeB van graad N35. Er bestaan magneten met betere graden, maar voor een relatief kleine versnelspanning van 30KeV is dit materiaal voldoende sterk. Voor de polepieces gebruiken ASI1018, een zacht ferromagnetisch staal dat geschikt is om gebruikt te worden in een CNC-machine. Deze materialen zullen meer in detail besproken worden in sectie 4.5.

### 4.2 Analytische afschatting magnetisch veld

Vooraleer we de lenseigenschappen van de lens kunnen simuleren, willen we een analytische schatting maken van het magnetisch veld B(z) op de symmetrieas van de lens. Hiervoor maken enkele belangrijke benaderingen om de berekeningen te vereenvoudigen.

Ten eerste veronderstellen we dat de magnetische veldlijnen volledig in de polepieces zullen blijven tot ze de gap tussen de polepieces bereiken, zonder dat er magnetisch veld op andere plaatsen naar buiten lekt. We zorgen ervoor dat dit een goede benadering blijft door de geometrie van de polepieces zo te ontwerpen dat het magnetisch veld nergens anders kan kortsluiten. We willen met andere woorden dat er geen andere paden C van de bovenkant naar de onderkant van de ringmagneet mogelijk zijn die een een kleinere/gelijkaardige reluctantie R =

R
C

dl
µ(l)A(l)

hebben. Daarnaast zorgen we ervoor dat de polepieces gladde en afgeronde oppervlakken hebben om randeffecten te voorkomen, aangezien magnetische veldlijnen de neiging hebben om zich te concentreren rond oppervlakken met een kleine kromtestraal, zoals randen en hoeken.

Om wiskundig te beschrijven waar de magnetische velden de polepieces verlaten of weglekken, is het gemakkelijk om gebruik te maken van magnetische poolladingen. De magnetische lading aan het oppervlak van een gemagnetiseerd volume wordt gegeven door σM = M · n met M de magnetisatie van het materiaal en n een normaalvector op het oppervlak. In het ideale geval zijn de polepieces zo gemagnetiseerd dat de magnetisatie altijd parallel ligtaan de zijoppervlakken ligt zodat σM = 0. Alleen bij de oppervlakken die aan de gap grenzen staat de magnetisatie loodracht op het oppervlak, waardoor we daar wel een poollading krijgen. In deze benadering hebben de polepieces dus enkel oppervlakteladigen aan de gap tussen de polepieces.

Een tweede belangrijke veronderstelling is dat de poolladingen aan de oppervlakken in de gap homogeen verdeeld zijn. Dit is een goede benadering als we een homogeen ferromagnetisch materiaal en een homogeen gemagnetiseerde ringmagneet gebruiken. De oppervlakken van de ringmagneet kunnen we immers ook als homogeen geladen oppervlakken beschouwen. De magnetische veldlijnen afkomstig van het magneetoppervlak zullen zich min of meer uniform doorheen de polepieces voortplanten zodat ook de gap-oppervlakken homogeen geladen zijn. Op deze manier wordt het magnetisch veld gereduceerd tot het veld veroorzaakt door twee homogeen geladen annula¹ met een tegengestelde, maar even

1Een annulus is een oppervlak opgespannen tussen twee concentrische cirkels.

14 — | Bachelorproef

4.2. ANALYTISCHE AFSCHATTING MAGNETISCH VELD

grote magnetische poollading ±σM.

Aan de hand van dit vereenvoudigd model kunnen we een analytische uitdrukking voor het magnetisch veld op de symmetrie-as terugvinden. We beginnen met 1 homogeen geladen annulus met een oppervlaktelading² +σM die zich rond de z-as op een hoogte z = 0 bevindt. De annulus heeft een binnenstraal van R1 en een buitenstraal R2. Natuurlijk is het niet mogelijk om een magnetische monopool zoals in dit systeem te maken, maar dit is slechts een tussenstap: later zullen we een tweede annulus met tegengestelde lading toevoegen. Dit systeem wordt getoond op Figuur 4.2.

Figuur 4.2: Systeem met 1 annulus rond een symmetrie-as. De annulus heeft een homogene oppervlaktepoollading gelijk aan σM, wat aanleiding geeft tot een magnetisch veld.

Het magnetisch veld in een bepaald punt r kan nu bepaald worden door de bijdragen van alle opeprvlakteelementen van de annulus te integreren, net zoals we zouden doen in het elektrostatisch geval. We moeten enkel de permittiviteit ε vervangen door de permeabiliteit µ. In ons geval zijn we enkel geïnteresseerd in het veld op de z-as, aangezien we in de paraxiale benadering zullen werken. Uit symmetrieoverwegingen kunnen we al zeggen dat enkel de component parallel met de z-as zal overblijven. We integreren de bijdragen van elk oppervlakte-elementje dS op de annulus aan het resulterend magnetisch veld, dit resulteert in de volgende berekening:

Bring(z) = Z

S

ez

- dB =

Z

S

cosθ

µ0σM
4π|r

′

2

dS =

µ0σM
4π

Z

S

cosθ
|r

′

2

dS

=

µ0σM
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
2 +ρ

2

dS =

µ0σM
4π

Z 2π

0

dφ

Z R2

R1

ρdρ

z
(z

2 +ρ

2)

3
2

=

µ0σMz
2

Z R2

R1

ρ
(z

2 +ρ

2)

3
2

dρ

Stel u = z

2 +ρ

2
, du = 2ρ dρ

=

µ0σMz
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
2 du =

µ0σMz
2

h
−u

−

1/2 iz

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
µ0σMz
2

1
q
z

2 +R

2
1

−

1
q
z

2 +R

2
2

(4.1)

Op Figuur 4.3 tonen we een plot van Bring voor parameters R1 = 1 en R2 = 2. Zoals we zouden verwach-

2Voorlopig kiezen we een arbitraire oppervlaktelading, in een latere sectie zullen we bespreken hoe we de juiste waarde voor σM kiezen.

HOOFDSTUK 4. EIGEN REALISATIE

ten uit de symmetrie van het systeem is het veld 0 in het midden van de ring. Vlak boven en onder de ring neemt het veld sterk toe in de zin weg van de ring, aangezien veldlijnen weg van positieve/noordelijke poolladingen bewegen. Onder de ring is het veld negatief, aangezien we de z-as als positieve richting hebben gekozen. Ver weg van de ring kunnen we de ladingsverdeling als een puntlading beschouwen en valt het veld af als 1
z

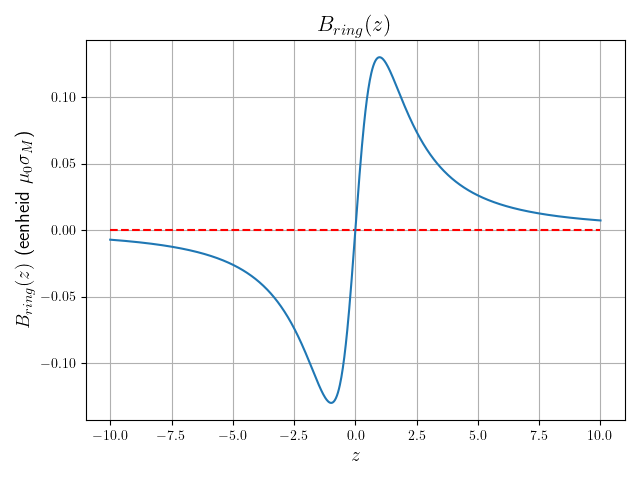
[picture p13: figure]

Figuur 4.3: Plot van Bring volgens vergelijking 4.1 voor parameters R1 = 1 en R2 = 2. Het veld is antisymmetrisch rond het midden van de ring, zoals men zou verwachten.

Door te werken met poolladingsdichtheden kunnen we nu eenvoudig het veld met twee tegengesteld geladen ringvormige oppervlakken berekenen. We kunnen simpelweg een superpositie maken van twee velden veroorzaakt door een enkel oppervlak, aangezien elektromagnetische velden lineair zijn. Het systeem dat we nu beschrijven wordt getoont op Figuur 4.4

Figuur 4.4: Systeem met 2 annula met een gapbreedte van d rond een symmetrie-as. De annula hebben homogene oppervlaktepoolladingen gelijk aan ±σM, wat aanleiding geeft tot een magnetisch veld. Dit is het systeem dat we beschouwen bij het afschatten van het magnetisch veld in onze lens.

16 — | Bachelorproef

4.2. ANALYTISCHE AFSCHATTING MAGNETISCH VELD

Het magnetisch veld wordt nu gegeven door:

B(z) = Bring
z+

d
2
−Bring
z−

d
2

=

µ0σM
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
2 +R
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
2 +R
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
2 +R
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
2 +R
2
2

(4.2)

Figuur 4.5 toont een plot van onze analytische afschatting van B(z) op de symmetrieas van de lens, met parameters R1 = 1, R2 = 2, d = 2.

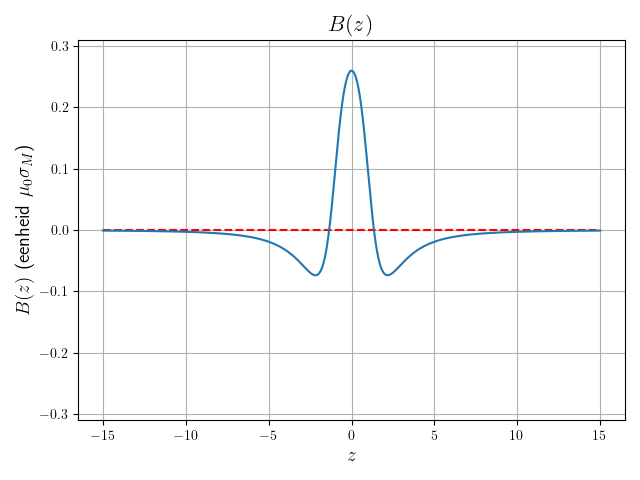
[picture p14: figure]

Figuur 4.5: Plot van B volgens vergelijking 4.2 voor parameters R1 = 1, R2 = 2, en d = 2. Het veld is nu symmetrisch rond het midden van de lens en maximaal in het midden van de lens, zoals men zou verwachten.

We verkrijgen op deze manier een sterk gepiekt magnetisch veld in het midden van de lens. Dit is exact wat we willen om een dunne lens met een bruikbare focale lengte te maken. Later zullen we onderzoeken hoe de geometrie van de ringoppervlakken het magnetisch veld verandert, en hoe dit de lenseigenschappen beïnvloedt.

Een belangrijke opmerking bij deze afschatting is dat deze in principe enkel geldt in het gebied −

d
2 <
z <

d
2

. De ringvormige ladingsoppervlakken zijn aan de buitenkanten immers begrensd door de polepieces, die een veel grotere permeabiliteit dan vacuum hebben. In het ideale geval is het magnetisch ¨ veld geconcentreerd in de polepieces zonder dat het weglekt, en geldt er voor z >

d
2
dat B(z) = 0. Op
bovenstaande figuur is echter te zien dat de velden buiten de lens heel wat kleiner zijn dan de velden in het centrum van de lens, en aangezien we in de paraxiale bewegingsvergelijkingen werken met B

2
zullen
deze randvelden zeer weinig invloed hebben wanneer we de vergelijking numeriek zullen oplossen.

Om later de aberratiecoefficienten te berekenen is het ook nuttig om de analytische afgeleiden van het ¨ veld te berekenen. Deze werden geevalueerd met Wolfram Mathematica en worden hieronder gegeven: ¨

Bring(z)

′ =

µ0σMz
2

z
R

2
2 +z

2

3/2

−

z
R

2
1 +z

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
1 +z

2

−

1
q
R

2
2 +z

2

(4.3)

HOOFDSTUK 4. EIGEN REALISATIE

B(z)

′ = Bring
z+

d
2

′
−Bring
z−

d
2

′
(4.4)

Bring(z)

′′ =

µ0σMz
2

3z

2
R

2
1 +z

2

5/2

−

3z

2
R

2
2 +z

2

5/2

−

1
R

2
1 +z

2

3/2

+

1
R

2
2 +z

2

3/2

!

+2

z
R

2
2 +z

2

3/2

−

z
R

2
1 +z

2

3/2
! | (4.5)

B(z)

′′ = Bring
z+

d
2

′′
−Bring
z−

d
2

′′
(4.6)

Deze functies worden getoond op Figuur 4.6.

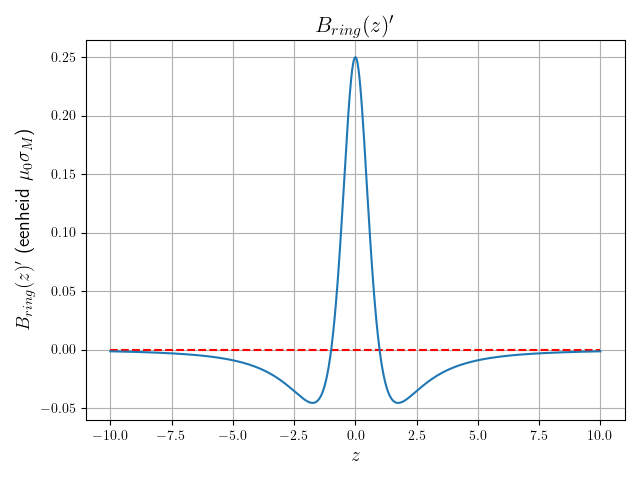
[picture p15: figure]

(a) Eerste afgeleide van Bring(z). | (b) Tweede afgeleide van Bring(z).

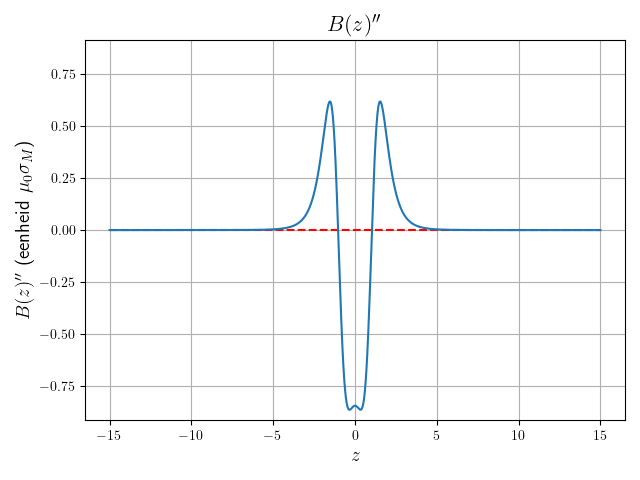
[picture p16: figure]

(c) Eerste afgeleide van B(z). | (d) Tweede afgeleide van B(z).

Figuur 4.6: Plots van de analytische afgeleiden van de magnetische velden voor 1 annulus en 2 annula met R1 = 1, R2 = 2, en d = 2. Deze afgeleiden zullen we later gebruiken om de asymtotische aberratiecoefficienten van de lens te berekenen. ¨

Onze analytische afschatting kunnen we numeriek controleren met het ionen- en elektronenoptica simulatieprogramma SIMION. Dit programma vindt de scalaire magnetische potentiaal door de Laplace-vergelijking voor een ladingsdichtheidverdeling op te lossen. Het programma kan dit door middel van finite-difference methoden; in dit geval werd het veld opgelost met een iteratieve over-relaxatie solver [8]. SIMION is bovendien ontworpen om axissymetrische problemen als 2D-problemen op te lossen. Om het numeriek gevonden veld te vergelijken met de analytische uitdrukking, simuleerden we een

18 — | Bachelorproef

4.3. MAGNETISCHE RELUCTANTIE VAN HET CIRCUIT

systeem met twee homogeen geladen ringoppervlakken met R1 = 2mm, R2 = 3mm en d = 4mm. De magnetische potentiaal werd berekend in een cilindrisch volume met een lengte van 6cm en een straal van 10mm, met Dirichlet randvoorwaarden (φ = 0 op de rand³
). De potentiaal op de symmetrie-as
werd geexporteerd, en het magnetisch ¨ | B(z) = δ φ δz
veld werd numeriek in Python berekend. Op Figuur 4.7 worden de analytische en numerieke velden vergeleken. Beide velden werden herschaald zodat Bmax = 1 aangezien we nog geen uitdrukking hebben voor σM. We zien een zeer goede overeenkomst, wat aangeeft dat onze analytische uitdrukking correct is.

Figuur 4.7: Vergelijking tussen analytische uitdrukking en numeriek gesimuleerd veld voor R1 = 2mm, R2 = 3mm en d = 4mm. We zien dat de velden zeer goed overeenkomen.

Belangrijkste bevindingen

We zijn er in geslaagd om een analytische afschatting op te stellen van het magnetisch veld veroorzaakt door de lens door de oppervlakken van de polepieces te modelleren als twee oppervlakken met een homogene, tegengestelde polladingsdichtheid. Het gebruiken van een analytische uitdrukking laat ons toe om ook de analytische afgeleiden te berekenen welke gebruikt kunnen worden om aberratiecoefficienten te schatten. Een vergelijking van de analytische uitdrukking ¨ met een numerieke oplossing m.b.v. SIMION van de Laplace-vergelijking geeft een vrijwel perfecte overeenkomst.

### 4.3 Magnetische reluctantie van het circuit

Nu we een benaderende analytische uitdrukking hebben gevonden voor het magnetisch veld voor ons lensontwerp, moeten we nadenken over welke waarde we moeten gebruiken voor de oppervlaktepoolladingsdichtheden σM.

De eerste factor waar we rekening mee moeten houden is de reluctantie van het circuit. De Nd-magneet heeft een remanent magneetveld Br

, dit is het magnetisch veld dat in de magneet overblijft wanneer we geen uitwendige magnetische velden aanleggen. Wanneer we de magneet in een magnetisch circuit met een gap gebruiken, zorgen de oppervlakteladingen aan de gap voor een demagnetiserend veld in de polepieces en de magneet dat het remanent veld tegenwerkt. Hierdoor is het werkelijke veld in de magneet Bm kleiner dan het remanent veld Br

3
In werkelijkheid willen we φ = 0 op oneindig, maar we kunnen geen oneindig groot volume simuleren.

HOOFDSTUK 4. EIGEN REALISATIE

Een elegante manier om dit effect wiskundig te beschrijven, is om de analogie te maken met elektrische weerstand en een magnetisch circuit te tekenen dat equivalent is met de geometrie van de lens. We maken eerst een magnetisch circuit equivalent⁴
aan de cilindrisch symmetrische lens, zoals wordt getoond op Figuur 4.8a. We krijgen door de oppervlakteladingen een demagnetiserend veld, getoond op Figuur 4.12b. Vervolgens tekenen we een symbolisch schema van dit circuit, getoond op Figuur 4.8c. De magneet is dan een bron van magnetomotorische kracht F. Zowel de magneet, de twee polepieces als de gap zorgen voor een reluctantie R in het circuit. De magnetische flux doorheen het circuit wordt dan gegeven door:

Φ =

F

Rtot

(4.7)

Te veel figuren?

(a) | (b) | (c)

Figuur 4.8: Illustratie van het magnetisch circuit equivalent aan dat van de lens. De gap veroorzaakt demagnetiserend veld dat ervoor zorgt dat het oppervlakteveld Bm van de magneet kleiner wordt dan haar remanent veld Br

. Dit kunnen we wiskundig beschrijven door de analogie te maken met elektrische circuits, waarbij de magneet een bron van magnetomotorische kracht, en de gap een reluctantie voorstellen.

Ten eerste weten we dat dezelfde flux doorheen het oppervlak van de magneet en het oppervlak van de gap stroomt, aangezien ∇·B = 0. Er geldt dus:

BmAm = BgAg | (4.8)

De totale reluctantie van het circuit kan berekend worden door de reluctanties in serie op te tellen Rtot = Rm +2Rp +Rg. Door de grote permeabiliteit van de polepieces µp is Rp verwaarloosbaar, dus Rtot = Rm +Rg. We houden dus enkel rekening met de reluctanties van de magneet en de gap. Uit de wet van Ampere in integraalvorm vinden we: `
Z

Γ

| H· dl ≈ Hgdg −Hmdm = Iint = 0 ⇔ Hm =

dg
dm
Hg | (4.9)

Waarbij dm en dg respecievelijk de dikte van de magneet en van de gap voorstellen. Nu weten we dat er in de gap geldt dat Hg =

Bg

µ0

, wat we kunnen invullen in 4.8:

Hg =

| BmAg
| µ0Ag

(4.10)

Door dit dan weer in te vullen in 4.9 vinden we de relatie:

Hm =

BmAgdg

µ0Agdm

⇔

| Bm
| µ0Hm

=

Agdm
Agdg
= Pc | (4.11)

4De figuur toont dus geen doorsnede van de lens, maar equivalent circuit dat niet meer axissymetrisch is.

20 — | Bachelorproef

4.3. MAGNETISCHE RELUCTANTIE VAN HET CIRCUIT
Deze coeffici ¨ | ent ¨ | Pc wordt de permeantiecoeccifient ¨ | genoemd en drukt de verhouding uit tussen de over-
gebleven magnetische fluxdichtheid en het demagnetiserend veld in de magneet [16]. Voor onze doelein-
den is het gemakkelijker om te werken met de intrinsieke permeantiecoeccifient ¨ | Pci, welke het verband
uitdrukt tussen het remanent veld Br en het demagnetiserend veld Hd.

Pci =

Br

µ0Hm

=

Bm + µ0Hm

µ0Hm

= 1+

Bm

µ0Hm

= 1+Pc = 1+

Agdm
Agdg
. | (4.12)

Het demagnetiserend veld zal enerzijds het remanent veld van de magneet tegenwerken, maar zal anderzijds ook het remanent veld zelf doen verkleinen. Hiervoor moeten we kijken naar de BH-curve van de magneet die we gebruiken. Figuur 4.9 toont de BH-curve van graad N35 NdFeB voor verschillende temperaturen. Op de figuur staan zowel de normale (Bm(Hd)) als de intrinsieke (Br(Hd)) BH-curve voor 6 verschillende temperaturen. In ons geval zijn we geïnteresseerd in de intrinsieke BH-curve bij kamertemperatuur, welke wordt gegeven door de gekromde blauwe lijn. We willen het zogenaamde werkingspunt van de magneet bepalen, dit is het (Br

,Hd) punt op de curve waarop het systeem zich bevindt. Dit doen we door het snijpunt te vinden tussen de interne BH-curve en de rechte gegeven door

Pciµ0Hm = Br

, de load line. Een voorbeeld wordt getoond op Figuur 4.10 waarbij Pci = 1.5.

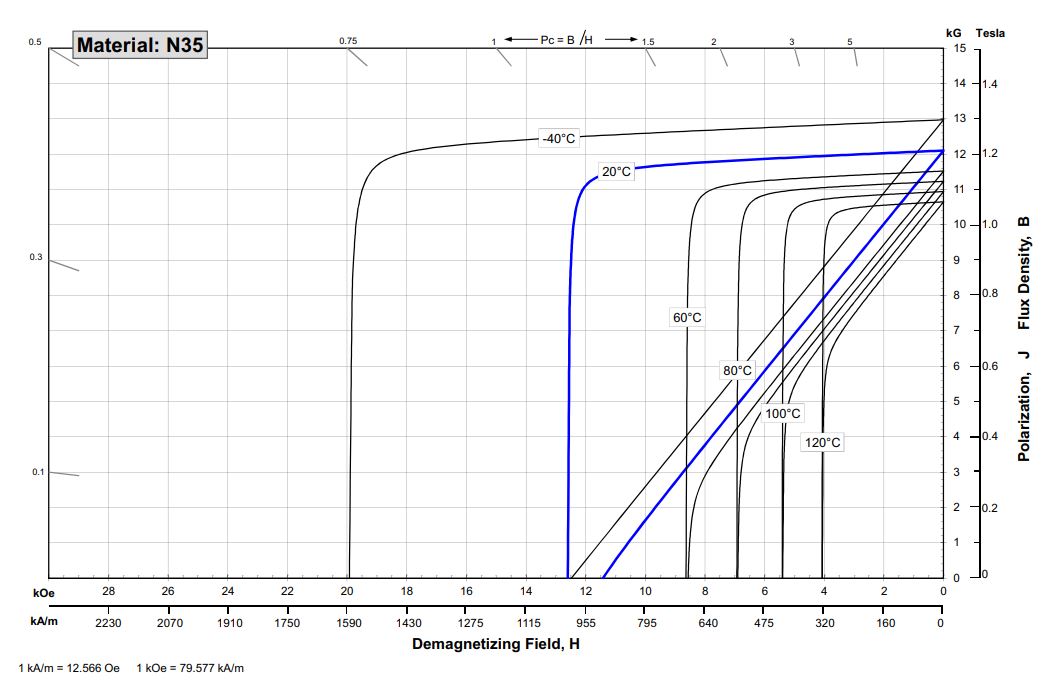
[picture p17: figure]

Figuur 4.9: BH-curve van graad N35 NdFeB voor verschillende temperaturen. Het aanleggen van een demagnetiserend veld doet de intrinsieke sterkte van de magneet licht verkleinen. Bij een zeer groot (extern) demagnetiserend veld passeren we de elleboog van de BH-curve en demagnetiseert de magneet, of wordt deze zelfs omgepoold. [5]

HOOFDSTUK 4. EIGEN REALISATIE

Figuur 4.10: Het werkingspunt van de magneet kunnen we vinden door het snijpunt te bepalen van
de BH-curve en de load line, waarvan de richtingscoeffici ¨ | ent afhant van de intrinsieke ¨
permeantiecoeccifient ¨ | Pc. Als het werkingspunt niet voorbij de elleboog van de curve ligt,
dan zal de magneet niet demagnetiseren.

Een we het veld gegenereerd door de magneet Bm = Br − µ0Hd hebben gevongen, kunnen we het magnetisch veld aan het oppervlak grenzend aan de gap kunnen berekenen door rekening te houden met de oppervlaktes van de polepieces Ag:

Bg =

BmAm
Ag

(4.13)

Dit kunnen we nu gebruiken om de juiste waarde voor σM te vinden. Voor een oneindige homogeen geladen vlakke plaat zou er gelden dat H = σm en dus dat B = µ0σM. In ons geval geldt er dus dat:

σM =

BmAm

Agµ0

(4.14)

De volledige analytische uitdrukking van het magnetisch veld op de optische as van de lens verkrijgen we door de ladingsdichtheid in te vullen in vergelijking 4.2 en wordt dus gegeven door de volgende vergelijking:

B(z) = BmAm
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
(4.15)

Belangrijkste bevindingen

Om de juiste waarde van de oppervlaktepoolladingsdichtheid te bepalen wordt er rekening gehouden met het demagnetiserend veld dat de fluxdichtheid in de magneet doet verkleinen. Een analogie met elektrische circuits laat ons toe om de permeantiecoeffici ¨ ent van het magnetisch circuit van de lens te berekenen, ¨ waarna het werkingspunt op de BH-curve gevonden kan worden. De oppervlaktepoolladingsdichtheid wordt berekend door te benaderen dat alle flux in de magneet wordt verdeeld over de oppervlakken van de polepieces.

22 — | Bachelorproef

4.4. IMPLEMENTATIE IN PYTHON

### 4.4 Implementatie in Python

Om de afhankelijkheid van de lenseigenschappen (f,zFi,zPi, etc.) van de lensparameters (R1,R2,dg,Br
, etc.)
te analyseren, hebben we een klasse in Python geschreven. Hiermee kunnen we snel de het magnetisch veld berekenen en plotten voor een bepaalde geometrie van de magneet en de polepieces, en vervolgens de paraxiale bewegingsvergelijkingen voor dit veld oplossen om zo de lenseigenschappen te berekenen.

### 4.4.1 Paraxiaal magnetisch veld

Om de afhankelijkheid van het magnetisch veld van de lensparameters te onderzoeken, maken we een functie die ons toelaat om de lensparameters met sliders aan te passen, terwijl het magnetisch veld continu wordt geupdated. In deze functie is ook het remanent veld Br

instelbaar, wat beter gedefinieerd moet worden aangezien de magneet ¨ niet 1 waarde voor Br heeft (maar een BH-curve). Deze instelling herschaalt de BH-curve zodanig dat het remanent veld voor Hd = 0

A
m

gelijk is aan de ingestelde waarde voor Br

. Een voorbeeld van een plot wordt getoond op Figuur 4.11 voor de parameters R1 = 0.8mm, R2 = 3.25mm, en dg = 0.8mm.

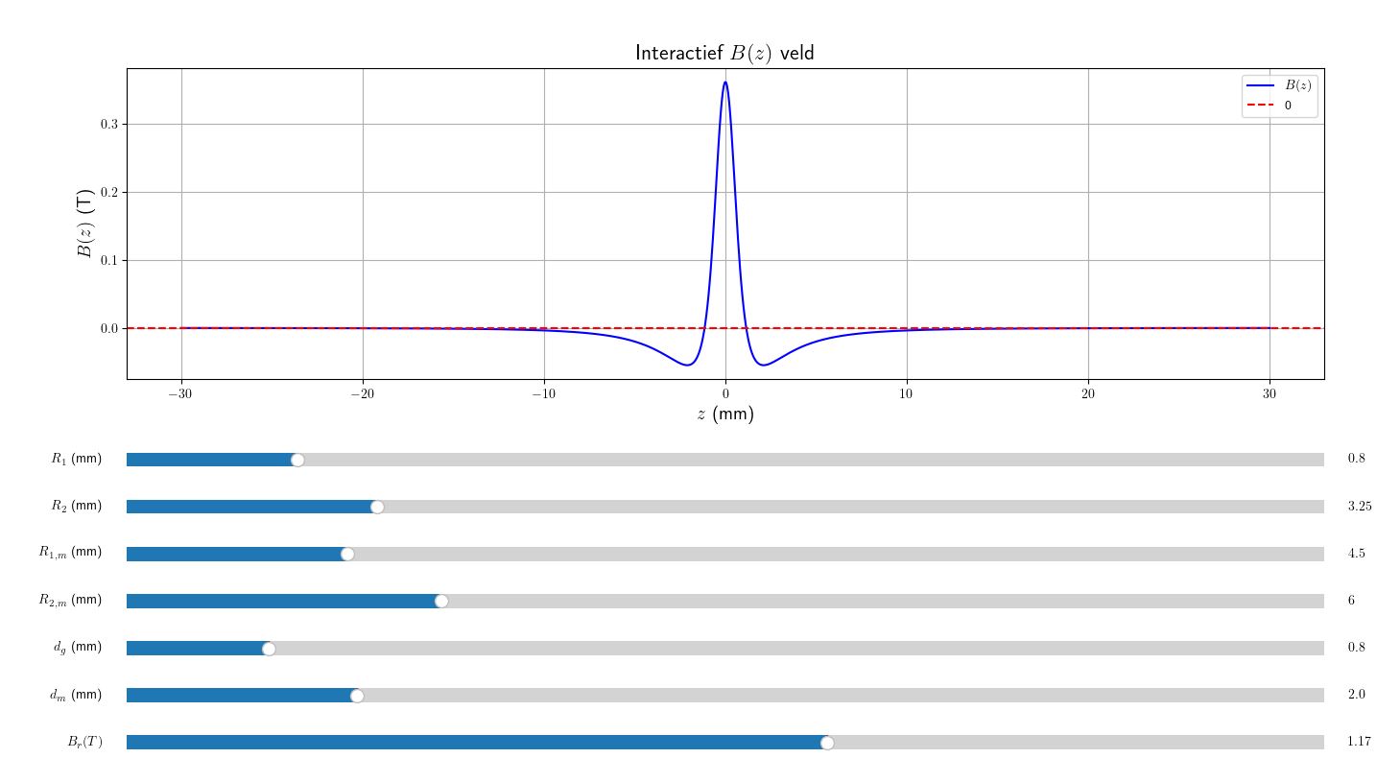
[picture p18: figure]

Figuur 4.11: Interactieve plot van B(z) in functie van de lensparameters. Deze functie kunnen we gebruiken om de afhankelijkheid van de verschillende parameters te bestuderen, en de lensparameters te optimaliseren om een gewenst magnetisch veld te krijgen. In dit geval gebruiken we de parameters R1 = 0.8mm, R2 = 3.25mm, en dg = 0.8mm. De Br
instelling zorgt voor
een herschaling van de BH-curve.

### 4.4.2 Paraxiale bewegingsvergelijkingen

Met de analytische uitdrukking voor het magnetisch veld kunnen we de paraxiale bewegingsvergelijking oplossen om uiteindelijk de lenseigenschappen van de lens te gaan voorspellen. Ter herinnering, de paraxiale bewegingsvergelijking wordt gegeven door:
d

2
r
dz²

+

η

2B(z)

2
4V
r = 0 | (4.16)

Hoewel de vergelijking er niet al te complex uit ziet, is het helemaal niet triviaal om ze voor eender welk magnetisch veld exact op te lossen. Slechts in enkele gevallen is er een analytische oplossing in gesloten vorm gekend. Een voorbeeld hiervan is Glaser’s bell-shaped field:

B(z) = B0
1+

z

2
a

2

(4.17)

De oplossing van vergelijking 4.16 kan voor dit veld worden uitgedrukt met goniometrische functies [13]. Het magnetisch veld kan ook benaderd worden door een constant veld:

B(z) = (
B0 z <

d
2
0 z >

d
2

(4.18)

In dat geval heleidt vergelijking 4.16 zich tot een harmonische oscillator in de lens. Echter, beide velden zijn niet fysisch, en slechts benaderingen van werkelijke magnetische velden. Figuur 4.12 geeft een vergelijking tussen deze twee velden en ons afgeschatte veld.

HOOFDSTUK 4. EIGEN REALISATIE

(a) | (b) | (c)

Figuur 4.12: Vergelijking tussen twee velden (Glaser’s field en constant veld) waarvoor de paraxiale bewegingsvergelijking analytisch oplosbaar is en ons analytisch afgeschat veld. Het Glaser’s field is gelijkaardig, maar heeft een bredere piek en valt trager af dan ons afgeschatte veld. Dit geeft een dikkere lens, wat ongewenst is.

We zien dat het Glaser’s field een goede benadering zou geven, maar de piek in het magnetisch veld is breder het veld vlakt trager af dan het veld van onze lens. Om accurate voorspellingen van onze lens te kunnen maken, kiezen we er daarom voor om de paraxiale beweginsvergelijking numeriek op te lossen en hieruit de lenseigenschappen te bepalen. Dit laat ons ook toe om later Monte Carlo simulaties van experimentele opstellingen uit te voeren, zodat we kunnen inschatten welke opstellingen ons bruikbare resultaten kunnen geven.

Om de paraxiale bewegingsvergelijking op te lossen, gebruiken we de solve ivp functie van de scipy.integrate bibliotheek. Het objectvlak z0 kunnen we naar wens instellen, en we gebruiken een 8ste orde Runge-Kutta methode (DOP853) om de twee lineair onafhankelijke oplossingen g en h te berekenen. De oplossing g(z), waarvoor geldt dat g(z0) = 1 en g

′
(z0) = 0, kunnen we dan gebruiken om de lenseigenschappen te berekenen. Ten eerste kijken we in welk vlak de twee asymtoten van g(z), de object en beeld asymtotische bundels, elkaar snijden. Dit vlak is het achterste/beeld hoofdvlak van de lens zPi. Ten tweede kijken we waar de beeld asymtotische bundel de symmetrie-as van de lens snijdt. Alle parallel bewegende elektronen zullen door dit punt passeren, dus dit is het brandpunt in het focusvlak zFi van de lens. De brandpuntsafstand kunnen we dan berekenen uit f = zFi −zPi. Door de symmetrie van het magnetisch veld kunnen we het object beeldvlak en het object focusvlak vinden uit zPo = −zPi en zFo = −zFi, Figuur 4.13 toont een voorbeeld van een numerieke oplossing van g. In dit geval vinden we een brandpuntsafstand van f = 15.50mm en bevindt het beeld hoofdvlak zich op zPi = −0.33mm van het midden van de lens.

Eens we de twee lineair onafhankelijke oplossingen hebben berekend, is het mogelijk om de baan van eender welk elektron af te beelden door een lineaire combinatie van de twee oplossingen te maken. Op deze manier kunnen we stralingsdiagrammen zoals Figuur 4.14, waarbij we de lens van de voorgaande figuur hebben gebruikt om een vergroting van M = 5 te krijgen. We tekenen op de figuur de drie hoofdstralen: de straal die door het midden van de lens gaat, en de straal die door het voorste brandpunt gaat. Deze drie kruisen elkaar in 1 punt achter de lens, waar het beeld gevormd wordt. Merk ook op dat de straal die door het midden van de lens gaat bijna niet wordt afgebogen, zoals men zou verwachten bij een dunne lens in de geometrische optica.

24 — | Bachelorproef

4.4. IMPLEMENTATIE IN PYTHON

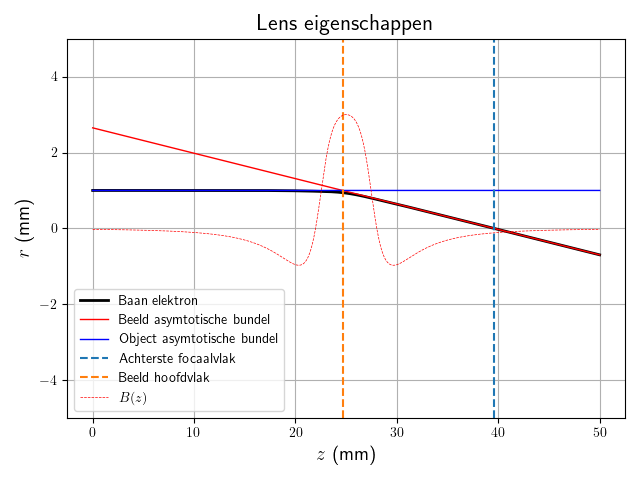
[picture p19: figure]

Figuur 4.13: Plot van numerieke oplossing van de paraxiale bewegingsvergelijking. De object en beeld asymptotische bundels snijden elkaar in het beeld hoofdvlak, en de beeld asymtotische straal snijdt de symmetrie-as in het achterste focaalvlak van de lens. Deze opstelling heeft de volgende parameters: R1 = 1.5mm,R2 = 5mm,d = 5mm,Bg = 0.447T,Φ = 30KeV.

Figuur 4.14: Voorbeeld van beeldvorming met een permanente magneetlens. We beschouwen hier de drie hoofdstralen: de straal die door het achterste brandpunt gaat, de straal die door het midden van de lens gaat, en de straal die door het voorste brandpunt gaat. In dit geval krijgen we een magnificatie M = 5.

### 4.4.3 Aberratiecoëfficienten

Met de analystische afschatting van het veld en de analytische afgeleiden zijn we in staat om de asymtotische aber-
ratiecoeffici ¨ | enten in vergelijkingen ¨ | 2.4 en 2.5 van de lens te berekenen. De uitdrukkingen van deze coeffici ¨ | enten ¨
worden hieronder gertoond [13].

D =

| | 3
| | 8 f + η
| | 2
| | 48V

Z +∞

| | −∞
| | 4η
| | 2
| | V B 4 +5B ′2 −BB′′
| | g
| | 3
| | hdz | (4.19)
| | CM = − η
| | 2
| | 4V

Z +∞
| | −∞ B
| | 2
| | ghdz | (4.20)

HOOFDSTUK 4. EIGEN REALISATIE

Merk op dat de oplossinge g en h van vergelijking 3.15 optreden. Deze opolssingen worden als dimensieloos beschouwd. Bovendien zijn deze oplossingen afhankelijk van de objectpositie z0, dus zijn ook de aberratiecoefficienten afhankelijk van de afstand tussen de lens en het object. Deze integralen zijn zeer zelden analytisch ¨ oplosbaar, en ook aangezien we geen anaylitische uitdrukkingen voor g en h hebben moeten we deze numeriek oplossen door de Riemann-som met een kleine ∆z te nemen. Sferische aberratie ook nog te berekenen

Belangrijkste bevindingen

We implementeerden een klasse in Python om de werking van de lens te simuleren om numeriek de lenseigenschappen voor een bepaalde geometrie te kunnen bepalen. De paraxiale bewegingsvergelijkingen worden opgelost met een 8ste orde Runge-Kuta methode om g en h te vinden, waarna beeldvorming gesimuleerd kan worden door lineaire combinaties van de twee oplossingen te maken. De aberratiecoeffici ¨ enten ¨ worden voorspeld door de integralen (met het analytische veld en haar afgeleiden) numeriek op te lossen.

### 4.5 Lensontwerp

Nu we in staat zijn om de banen van elektronen door het magnetisch veld van een lens te simuleren, kunnen de parameters van de lens gaan optimaliseren om een geschikte dunne lens te maken. Hierbij moeten we rekening houden met het volgende:

1. We willen liefst een dunne lens, dus willen we zPi ≈ 0. Dit betekent dat dat B(z) een smalle piek moet vertonen.
2. We willen een lens die we in de MIRA microscoop kunnen gebruiken. Concreet betekent dit dat we een focale lengte willen die rond de 5 − 10mm ligt. Hiervoor moet σM voldoende groot zijn, en moet R1 voldoende klein zijn zodat de ladingen zich niet te ver van de optische as bevinden.
3. We willen dat de berekende aberratiecoeffici ¨ | enten ¨ | D en CM niet al te groot zijn om vervormde beelden te
voorkomen. Typische waarden voor D en CM zijn respectievelijk ∼ 0.5mm⁻²
| | en ∼ 1 − 3 [3] [14]. We
proberen daarom de coeffici ¨ | enten onder deze waarden te houden. ¨
4. Figuur 4.10 toonde de BH-curve van graad N35 NdFeB. We willen ten eerste dat het werkingspunt de elleboog van deze curve niet overschrijdt, omdat het remanent veld van de magneet dan snel zou afnemen of zelfs zou omkeren. Echter, de elleboog bevindt zich ongeveer bij Br = 1.1T,µ0Hd = 1.2T, dus bij

µ0Hd > Br
. Het is met andere woorden niet mogelijk om de magneet (bij kamertemperatuur) in een circuit te demagnetiseren zonder een extern magnetisch veld aan te leggen.

Echter, het is nog steeds gewenst dat het demagnetiserend veld zo klein mogelijk blijft; een groot demagnetiserend veld zorgt nog steeds voor een instabieler circuit. Een exterm demagnetiserend veld of een hogere temperatuur kunnen de magneet in dat geval makkelijker irreversiebel doen demagnetiseren. In onze berekening van Hd hebben we bovendien een versimpeld en geïdealiseerd systeem beschouwd; dit is slechts een schatting van de exacte waarde. De werkelijke waarde van Hd kan zelfs tot ∼ 1.5 keer groter zijn dan
de analytisch geschatte waarde [21]. Dit betekent dat we de interne permeantiecoeccifient ¨ | Pci =
| | Br µ0Hd liefst
zo groot mogelijk houden. Om ongewenste effecten te voorkomen, stellen we voor onszelf een (arbitrair gekozen) ondergrens van Pci > 2.5 in. Figuur 4.16 toont het werkingspunt bij deze ondergrens.
5. Een andere belangrijke factor waarmee we rekening moeten houden is de BH-curve van de polepieces. We gaan er in vergelijking 4.13 van uit dat alle veldlijnen vanuit de magneet worden uitgespreid over de oppervlaktes van de polepieces. In het algemeen is de oppervlakte van de polepieces kleiner dan die van de magneet, waardoor de veldlijnen zullen concentreren en de fluxdichtheid toeneemt. Dit betekent dat we moeten oppassen dat de polepieces niet gesatureerd raken, want dan zou er magnetisch veld weglekken wat allerlei ongewenste effecten met zich meebrengt. Om een bovengrens voor Bg vast te leggen, moeten we naar de BH-curve van ASI1018 kijken. Deze wordt getoond op Figuur 4.15. Er treedt saturatie op wanneer deze curve afvlakt, dus we willen in het lineair deel van de curve blijven werken. De curve vlakt af bij ∼ 1.5T, dus willen we dat de maximale fluxdichtheid in onze polepieces hieronder blijft. Bij het ontwerp proberen we de parameters zo te kiezen dat Bg < 1.25T.
6. Ten slotte moeten we rekening houden met geometrische beperkingen. De binnenstraal R1 moet groter dan ∼ 0.5mm zijn om te voorkomen dat de elektronen door de gaten van beide polepieces kunnen en niet op een oppervlak botsen. De buitenstraal R2 moet uiteraard kleiner zijn dan de binnenstraal van de magneet
26 — | Bachelorproef

4.5. LENSONTWERP

R1,m, maar kiezen we best nog kleiner (R2 < R1,m −1mm) om te voorkomen dat het magnetisch circuit kan kortsluiten doordat de veldlijnen van de magneet naar de oppervlakken van de polepieces kunnen overslaan. Bovendien mogen de toleranties van het ontwerp niet te klein worden voor de CNC machines waarmee de polepieces gemaakt worden. Bij voorkeur zijn de gekozen afmetingen ook afgeronde getallen, zodat er bv. standaard boorgaten kunnen worden gebruikt bij het produceren van de polepieces. Ten slotte kunnen we de afmetingen van de magneet niet vrij kiezen; deze worden niet op maat gemaakt, dus we hebben keuze tussen een beperkt aantal dimensies.

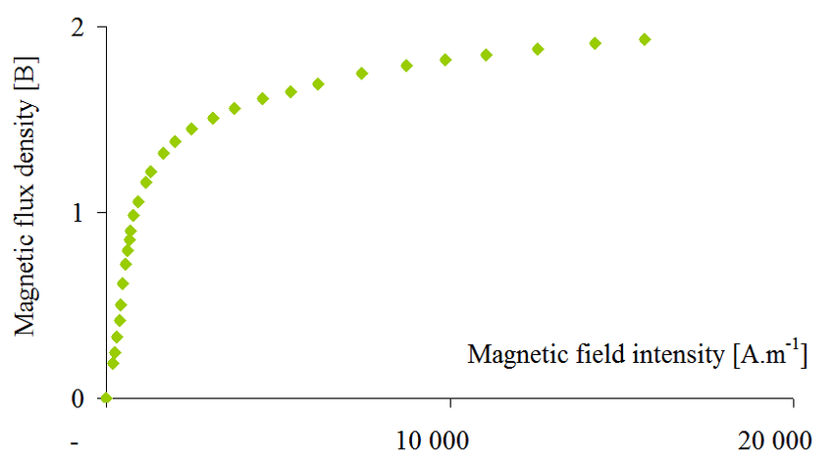
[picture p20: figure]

Figuur 4.15: BH-curve van ASI1018. Het is belangrijk dat de curve bij onze waarde voor Bg lineair is, zodat er geen saturatie optreedt en er geen magnetisch veld weglekt. [6]

Figuur 4.16: Het werkingspunt van de magneet bij Pci = 2.5. Dit is de ondergrens die we voor voor ons ontwerp kiezen om te voorkomen dat er demagnetisatie van de magneet zou optreden. Het werkingspunt kan door een groot aantal onvoorziene factoren dichter dan verwacht bij de elleboog van de curve liggen, dus moeten we ervoor zorgen dat Pci groot genoeg blijft.

HOOFDSTUK 4. EIGEN REALISATIE

### 4.5.1 Simulatie van lenseigenschappen

Zoals beschreven in hoofdstuk 4.4, hebben we in Python een klasse geschreven waarmee we snel de lenseigenschappen van een bepaald lensontwerp kunnen berekenen. Het bepalen van de optimale lensparameters kunnen we hiermee bepalen gewoonweg via trial-and-error, door steeds de lensparameters aan te passen en de lenseigenschappen te berekenen. Het is echter nuttig om de invloed van de verschillende parameters te onderscheiden om ze individueel te kunnen onderzoeken. Hiervoor kiezen we voor een bepaalde lensparameter een boven en ondergrens en berekenen we (voor vaste overige lensparameters) de lenseigenschappen voor een groot aantal punten tussen deze twee grenzen. De resultaten kunnen we dan op een grafiek weergeven om zo efficienter de lensparameters te ¨ optimaliseren. We hebben voor vier verschillende lensparameters (R1, R2, dg, en Br) een functie geïmplementeerd waarmee we dit soort grafieken kunnen plotten. Op deze grafieken plotten we ook de permeantiecoeffici ¨ ent ¨

5 Pci
om te voorkomen dat we de reluctantie van het magnetisch circuit niet te groot maken. Het varieren van de de ¨ afmetingen van de magneet heeft enkle een verandering van Bm als gevolg, en kunnen dus ook gemodelleerd wor-
den door het varieren van ¨ | Br
. Naast de vier genoemde lensparameters maken we ook een grafiek voor variaties van de versnelspanning⁶ T. Merk op dat de afgeleiden van de lenseigenschappen in functie van T van een maat zijn voor de chromatische aberratie. Hoe groter de afhankelijkheid van de versnelspanning, hoe groter de fouten bij een kleine variatie van de energie/versnelspanning. Voorbeelden van deze plots worden getoond op Figuur 4.17 en 4.18.
(a) (b)

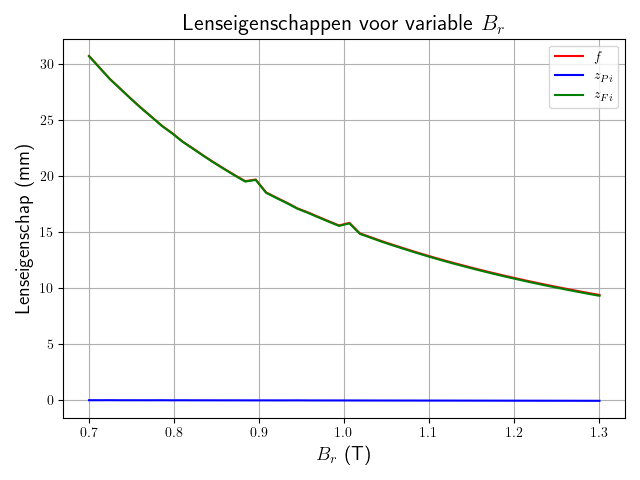
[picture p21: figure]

(c) (d)

Figuur 4.17: Plots van lenseigenschappen en reluctantieterm in functie van de geometrie van de lens. Deze plots geven een goed beeld van hoe de parameters aangepast kunnen worden om de lenseigenschappen naar wens te optimaliseren. Naast de reluctantieterm moet er ook rekening gehouden worden met de maximale fluxdichtheid in de polepieces, welke niet te hoog mag zijn om saturatie-effecten te voorkomen.

5Voor Br doen we dit niet aangezien Pci onveranderd blijft onder een herschaling van de BH-curve.
6Ook voor T heeft het geen zin om Pci te plotten aangezien dit een eigenschap van de lens (en niet de microscoop) is.
28 — | Bachelorproef

4.5. LENSONTWERP

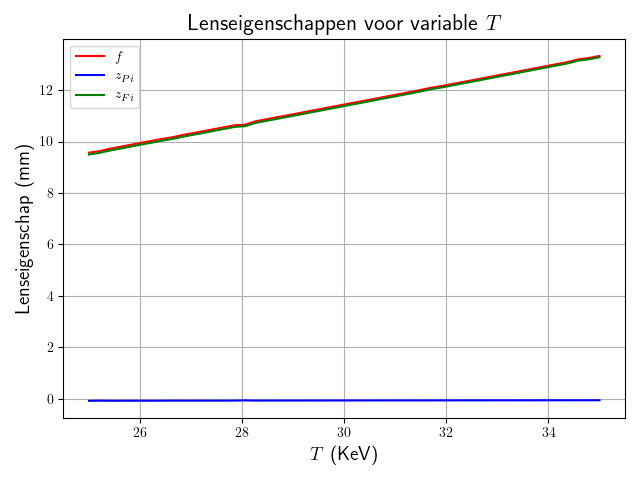
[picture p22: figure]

Figuur 4.18: Plot van de lenseigenschappen in functie van de versnelspanning Φ. De afgeleiden van de lenseigenschappen naar de versnelspanning geven een maat voor de chromatische aberratie.

We impementeren een gelijkaardige functie om ook de aberratiecoeffici ¨ | enten ¨ | D en CM in functie van de lenspara-
meters R1, R2, dg, en Br

te bepalen. Zoals eerder vermeld zijn D enCM afhankelijk van de objectafstand z0, dus om een correcte vergelijking tussen verschillende lensiegenschappen te maken, houden we de objectafstand constant op z0 = 25mm, wat een typicshe afstand is bij een focales lengtes waarbij we werken ()f ∼ 10mm). Grafieken
van de aberratiecoeffici ¨ | enten in functie van de lensparameters worden getoond op Figuur ¨ | 4.19.

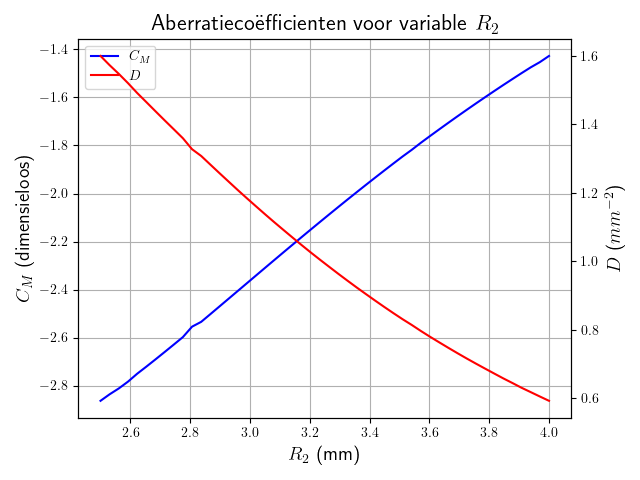
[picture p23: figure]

(a) (b)
(c) (d)
Figuur 4.19: Plots van aberratiecoeffici ¨ | enten ¨ | D en CM in functie van de geometrie van de lens bij z0 =
25mm. Deze plots geven een goed beeld van hoe de parameters aangepast kunnen worden om de aberratiecoeffici ¨ enten te minimaliseren. ¨

HOOFDSTUK 4. EIGEN REALISATIE

Met deze hulpmiddelen kunnen we een geschikte set lensparameters kiezen die een optimale combinatie geeft van gewenste lenseigenschappen, klein demagnetiserend veld en minimale aberratiecoeffici ¨ enten. We hebben gekozen ¨ voor de volgende lensparameters:

Lensparameter | Waarde
R1 | 0.8mm
R2 | 3.25mm
dg | 0.8mm
R1,m | 4.5mm
R2,m | 6mm
dm | 2mm
Br | 1.17T

Tabel 4.1: Gekozen lensparameters die een optimale lenswerking geven. We gebruiken een N35 graad NdfeB magneet, die een remanent veld van ongeveer 1.17T heeft.

In de tabel staat er een enkele waarde voor het remanent veld, maar zoals eerder vermeld moeten we in feite heel de BH-curve in rekening nemen. Deze hangt af van de graad van de magneet die we gebruiken. De ringmagneten werden geleverd door Magnet Outlet [2]. De gebruikte magneet is van de graad N35, maar jammer genoeg is er geen datasheet met alle specificaties van de magneet beschikbaar [20]. We gebruiken daarom de BH-curve getoond op Figuur 4.9 bij het bepalen van de lenseigenschappen. De gekozen lensparameters geven aanleiding tot de volgende lenseigenschappen:

Lenseigenschap | Waarde
f | 11.437mm
zPi | −0.060mm
zFi | 11.377mm
Pci | 2.575
Bmax | 1.120T
D | 0.994mm⁻²
CM | 0.840

Tabel 4.2: Lenseigenschappen voor de gekozen lensparameters.

Deze lenseigenschappen voldoen aan onze eisen. De lens is bij benadering een dunne lens met een focale lengte die voldoende kort is voor de MIRA SEM. Het demagnetiserend veld is niet te groot en de maximale fluxdichtheid in de polepieces is voldoende klein zodat we ons nog steeds in het lineair gebied van de BH-curve op Figuur 4.15
bevinden. De aberratiecoeffici ¨ | enten ¨ | CM is ook vergelijkbaar met typische waarden voor bruikbare elektronenlen-
zen. De coeffici ¨ | ent ¨ | D is echter redelijk groot vergeleken met literatuurwaarden. Het is echter zeer moeilijk om
deze aberratiecoefficienten nog kleiner te maken. Als we kijken naar Figuren ¨ | 4.19 en 4.17, dan zien we dat het
veranderen van een van de lensparameters om D te verkleinen steeds ongewenste neveneffecten heeft. Het vergroten van R1 zorgt voor een kleinere focale lengte en een grotere fluxdichtheid in de polepieces. Ook het vergtoten van R2 zal f doen toenemen, en verkleint de afstand tussen de buitenkant van de polepieces en de binnenkant van de magneet waardoor de kans op een kortsluiting in het circuit groter is. Het vergroten van dg tot voorbij het maxima van D geeft dan weer een te kleine Pci en een zwakkere magneet gebruiken zodat Br verkleint geeft ook een te lange focale lengte. Om deze redenen beargumenteren we dat dit de ideale set parameters is ook als is D groot t.o.v. typische waarden uit de literatuur. Bovendien kunnen we de distorie op andere manieren experimen-
30 — | Bachelorproef

4.5. LENSONTWERP

teel minimaliseren, hierover meer in hoofdstuk 4.6.

Eens we deze parameters hebben vastgelegd, moeten we een driedimensionaal model van de lens maken zodat de onderdelen door een CNC-service geproduceerd kunnen worden. We kiezen ervoor om het ontwerp in FreeCAD te maken. Dit kunnen we eenvoudig doen door een 2D sketch van een doorsnede van de lens met de gekozen afmetingen te maken, en vervolgens met de Revolution functie van het programma een cilindrisch symmetrisch onderdeel op basis van de sketch te maken. Figuur 4.20a toont de 2D sketch met de afmetingen en enkele screenshots van het driedimensionaal model van de polepieces. We zorgen ervoor dat de polepiece zo min mogelijk scherpe hoeken heeft, zodat het magnetisch veld nergens aan de buitenkant concentreert of weglekt. Vervangen door technische tekeningen?

(a) (b)
(c) (d)

Figuur 4.20: Verschillende aanzichten en een 2D sketch van het ontwerp van de polepieces in FreeCAD.

Deze stepfile hebben we opgestuurd naar de CNC-service Protolabs Network [1]. We hebben de polepieces laten maken in ASI1018 waarbij het oppervlak gepassiveerd wordt. Dit is een behandeling met HNO3 waarbij er een dunne laag metaaloxide aan de buitenkant van het ASI1018 gevormd wordt [18]. Op deze manier wordt er voorkomen dat het materiaal begint te roesten, wat de permeabiliteit kan veranderen of oppervlakte-effecten veroorzaakt welke het magnetisch veld zullen beïnvloeden.

Belangrijkste bevindingen

De optimale lensparameters worden bepaald door een trial-and-errorproces ondersteund door variatieplots waarbij telkens 1 parameter wordt aangepast. Hiervoor hebben we in de Python klasse functies
geïmplementeerd die de lenseigenschappen, aberratiecoeffici ¨ | enten en permeantieco ¨ | effici ¨ | ent voor een va- ¨
riabele lensparameter berekenen en plotten. We vonden met deze methodologie een set lensparameters die aan de gewenste eigenschappen voor de lens voldoet, en ontwierpen de driedimensionale geometrie voor de lens in FreeCAD.

HOOFDSTUK 4. EIGEN REALISATIE

### 4.6 Karakterisatie in de microscoop

### 4.7 Experimentele bepaling focale lengte

### 4.7.1 Mesh shadowgraph methode

Om de focale lengte en eventueel andere lenseigenschappen van de lens te bepalen gebruiken we een aangepaste versie van de rear mesh shadowgraph methode beschreven in [4]. Het algemene principe van deze methode bestaat er in om met behulp van de lens een divergerende elektronenbundel te maken. De focale lengte kan dan worden afgeleid door te meten hoe divergent deze elektronenbundel juist is. Concreet kunnen we dit meten door een fijnmazig rooster (mesh grid) achter de lens in de divergerende bundel te plaatsen, zodat er een uitvergroot schaduwbeeld op de detector wordt geworpen. De magnificatie van het schaduwbeeld is dan een maat voor de divergentie van de elektronenbundel. Hieronder werken we enkele gevallen wiskundig uit.

Een van de methodes beschreven in [4] maakt gebruik van een puntbron op de optische as die we een afstand z > f van de lens plaatsen. We veronderstellen dat we een dunne lens gebruiken, waardoor we de dunne lensformule kunnen gebruiken:
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
(4.21)

De puntbron wordt dan achter de lens afgebeeld op een afstand z

′ > f van de lens. We plaatsen nu een grid met een nauwkeurig gekende periode van e1 op een afstand b van de lens, waarbij b > z

′
zodat de elektronenbundel
wordt gefocusseerd voor het grid. Op een afstand d van het grid plaatsen we een elektronendetector. Het beeld van de puntbron op z

′ veroorzaakt nu een divergerende elektronenbundel die een uitvergroot schaduwbeeld van het grid op de detector werpt. De opstelling wordt getoond op Figuur 4.21.

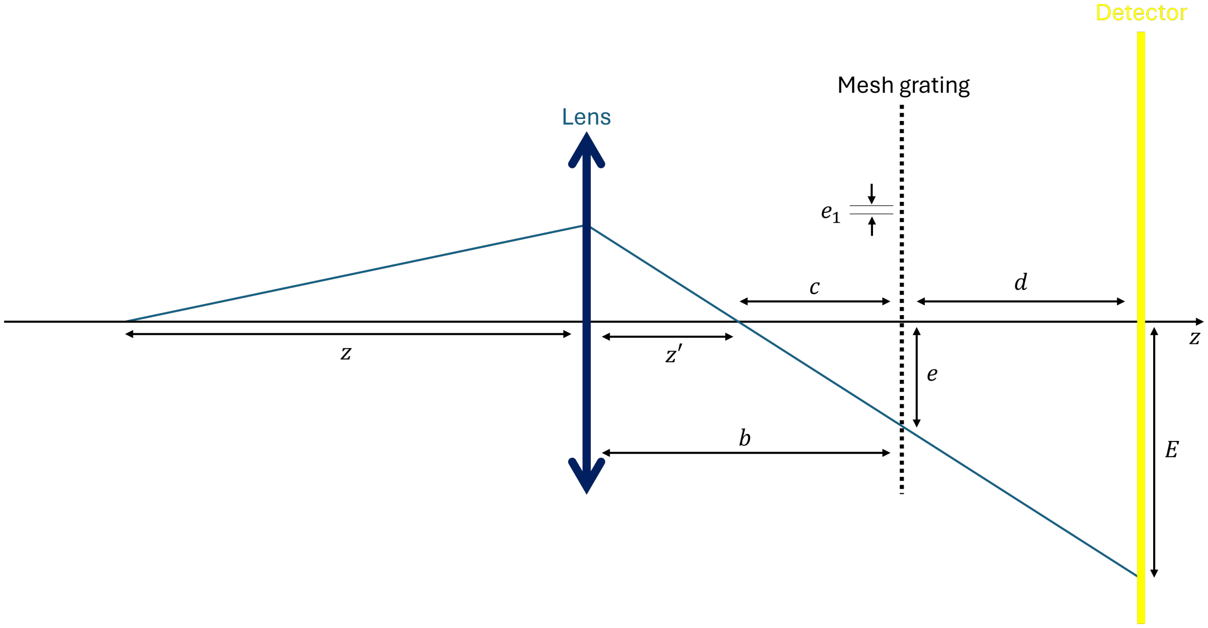
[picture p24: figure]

Figuur 4.21: Rear mesh shadowgraph methode voor een puntbron voor het focaalvlak van de lens. Door de magnificatie M =

E
e

te meten is het mogelijk om het beeldpunt z

′
en de focale lengte f
te bepalen.

Op het detectorbeeld meten we de grootte van 1 of meerdere afgebeeldde roosteropeningen, welke we aanduiden met E. De werkelijke afmeting van de roosteropeningen duiden we aan met e = ne1 met n het aantal roosteropeningen dat we beschouwen. De magnificatie van het schaduwbeeld is gelijk aan M E
e

. Uit gelijkvormigheid van driehoeken volgt dan:
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
= M = 1+

d
c

(4.22)

Dit kunnen we omvormen om c te vinden:

c =

d
M −1

(4.23)

Hiermee kunnen we eenvoudig de beeldafstand z

′ bepalen:

z

′ = b−c = b−

d
M −1

(4.24)

Met de beeldafstand kunnen we de focaalafstand berekenen door vergelijking 4.21 om te vormen. In het experiment dat we in deze thesis zullen uitvoeren passen we de voorgaande methode op twee manieren aanpassen,

32 — | Bachelorproef

4.7. EXPERIMENTELE BEPALING FOCALE LENGTE

welke hieronder in meer detail worden uitgelegd.

Het is mogelijk dat de werkelijke focale lengte van de lens groter is dan de voorspelde focale lengte, waardoor de
initiele puntbron achter het voorste focaalvlak van de lens ligt. In dat geval wordt er geen re ¨ | eel beeld achter de ¨
lens, maar een virtueel beeld voor de lens gevormd. Dit wordt getoond op Figuur 4.22.

Figuur 4.22: Rear mesh shadowgraph methode voor een puntbron achter het focaalvlak van de lens. De elektronenbundel wordt nu niet gefocusseerd in een punt, maar de elektronenbundel is nog steeds divergerend wat een magnificatie M > 1 geeft.

Het is met deze opstelling nog steeds mogelijk om op deze manier de focale lengte te berekenen. Opnieuw vinden we uit gelijkvormigheid dat:
e
z

′ +b

=

E
z

′ +c+d

⇔

E
e

= M = 1+

d
z

′ +b

(4.25)

Dit omvormen naar z

′ geeft:

z

′ = b−

d
M −1

(4.26)

Merk op dat dit exact dezelfde formule geeft als bij een reeel beeld ( ¨ | 4.24). Opnieuw gebruiken we 4.21 om f te
berekenen.

Een mogelijke manier om de mesh shadowgraph methode te vereenvoudigen is om een paralelle i.p.v. een conische elektronenbundel op de lens in te sturen. In dat geval is z = ∞, waardoor uit 4.21 volgt dat z

| ′ = f . We kunnen
dezelfde procedure als in de originele methode gebruiken om c te bepalen, maar nu kunnen we de focale lengte rechtstreeks bepalen uit f = b−c. Figuur 4.23 toont de opstelling in dit geval.


Figuur 4.23: Rear mesh shadowgraph methode voor een parallelle bundel. Door het gebruik van een parallelle bundel worden de inkomende elektronenbundels door de lens gefocusseerd in het focaalvlak achter de lens, wat de bepaling van de focale lengte iets vereenvoudigt.

In principe kan deze methode ook uitgebreid worden om de chromatische en sferische aberratiecoeffici ¨ | enten van ¨
de lens te berekenen. De sferische aberratiecoeffici ¨ | ent kan worden afgeleid door de afgebeeldde grootte van de ¨
individuele roosteropeningen uit te zetten in functie van de afstand tot de optische as van het systeem. Immers, hoe

HOOFDSTUK 4. EIGEN REALISATIE

verder de roosteropening zich van de optische as bevindt, hoe groter de hoek α tussen de elektronen en de optische as. Sferische aberratie kan worden uitgedrukt als ∆z

′ = −Csα
2
, dus door z

′ voor verschillende waarden van α te
berekenen kunnen we de sferische aberratiecoeffici ¨ | ent ¨ Cs fitten. De chromatische aberratie kunnen we berekenen
door de versnelspanning van de micrscoop aan te passen. De chromatische aberratiecoeffici ¨ | ent ¨ Cf kunnen we dan
berekenen uit ∆f
f = Cf

∆V
V

### 4.7.2 Monte Carlo simulatie van het experiment

34 — | Bachelorproef

# 5 Vooruitzicht


# 6 Besluit


Bibliografie

# Bibliografie

[1] Hubs.com. 31
[2] Neodymium ring magnet Ø12mm x Ø9mm x 2mm. 30
[3] T. M. Abbas. Correction of distortion aberration in electron magnetic lenses. International Journal of Applied Physics, 3(2):1–5, 2016. 26
[4] L. T. Almaraz. Measurement of the focal properties of a magnetic electron lens using the shadowgraph method. Dissertations and Theses, (Paper 6279). 32
[5] Arnold Magnetic Technologies Corp. Neodymium-Iron-Boron Magnet Grades Summary Product List & Reference Guide. Arnold Magnetic Technologies Corporation, 770 Linden Ave., Rochester, NY 14625-2764 USA, 2019. Rev. 181031 / 151021a. 21
[6] D. Buchenau, G. Schmidt, and S. Eckert. Contact-less magneto-elastic torsional sensor based on phase-shift measurements. Measurement Science and Technology, 25(7):075901, may 2014. 27
[7] H. Busch. Berechnung der bahn von kathodenstrahlen im axialsymmetrischen elektromagnetischen felde. Annalen der Physik, 386(25):974–993, 1926. 3
[8] D. A. Dahl and D. J. Manura. SIMION 8.1 User Manual. Scientific Instrument Services, Inc. (Adaptas Solutions), Palmer, MA, 2008. 18
[9] L. de Broglie. Recherches sur la theorie des quanta ´ | . PhD thesis, University of Paris, Paris, 1924. Published
in Annales de Physique 10e serie, t. III, 22-128 (1925). ´ | 3
[10] N. M. Geekiyanage, M. A. Balanant, E. Sauret, S. Saha, R. Flower, C. T. Lim, and Y. Gu. A coarsegrained red blood cell membrane model to study stomatocyte-discocyte-echinocyte morphologies. PLOS ONE, 14(4):e0215447, 2019. 6
[11] G. Guzzinati. Exploreren van elektron golffunctie manipulatie in transmissie–elektronenmicroscopie. Master’s thesis, Universiteit Antwerpen, 2015. 7
[12] P. Hawkes. The correction of electron lens aberrations. Ultramicroscopy, 156:A1–A64, 2015. 3
[13] P. W. Hawkes. Electron Optics and Electron Microscopy. Taylor & Francis LTD, 10-14 Macklin Street, London, 1972. 5, 6, 8, 9, 23, 25
[14] JEOL. Aberration. 26
[15] Y. Jiang, Z. Chen, Y. Han, P. Deb, H. Gao, S. Xie, P. Purohit, M. W. Tate, J. Park, S. M. Gruner, V. El-
ser, and D. A. Muller. Electron ptychography of 2d materials to deep sub-angstr ˚ | om resolution. ¨ | Nature,
559(7714):343–349, 2018. 5
[16] Magnetic Materials Producers Association. Permanent Magnet Guidelines. Magnetic Materials Producers Association, 8 South Michigan Avenue, Suite 1000, Chicago, Illinois 60603. 21
[17] M. Malac, J. A. M. Calzada, M. Salomons, D. Homeniuk, P. Price, M. Cloutier, M. Hayashida, D. Vick,
S. Chen, S. Yakubu, Z. D. Wen, M. Leeson, M. Kamal, J. Pitters, J. Kim, X. Wang, O. Adkin-Kaya, and R. Egerton. Nanomi: An open source electron microscope hardware and software platform. Micron, 163:103362, 2022. 3
[18] R. Maller. Passivation of stainless steel. Trends in Food Science & Technology, 9(1), 1998. 31
[19] V. Shiltsev. Electron lenses: historical overview and outlook. Journal of Instrumentation, 16(03):P03039, 2021. 3
[20] V. Soares. privecommunicatie, 12 2025. ´ | 30
[21] Steve Constantinides. Magnet faqs. 26
[22] M. M. Training. Transmission electron microscopy. myscope.training. 3, 6, 7

Bibliografie; Bachelorproef

[23] G. Van Tendeloo, S. Bals, S. Van Aert, J. Verbeeck, and D. Van Dyck. Advanced electron microscopy for
advanced materials. Advanced Materials, 24(42):5655–5675, 2012. 3

[24] M. Winey, J. B. Meehl, E. T. O’Toole, and T. H. Giddings. Conventional transmission electron microscopy.
Molecular Biology of the Cell, 25(3):319–323, February 2014. 6

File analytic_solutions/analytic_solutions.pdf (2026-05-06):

Analytische Oplossingen Homogene Pooldichtheid

## 1 Vlakke oppervlakken


Bz,ring(z) = µ0σmz
2

1
p
z

2 + R²
1

−

1
p
z

2 + R²
2

!
(1)


Bz(z) = Bz,ring
z −

d
2

− Bz,ring
z +

d
2
(2)

1

## 2 Gekantelde oppervlakken

Een mogelijke uitbreiding die niet in de thesis wordt vermeld bestaat erin om de annuli te kantelen. Het oppervlak is dan de mantel van een afgeknotte kegel. Dit geeft een veel complexere uitdrukking voor het magnetisch veld welke werd berekend m.b.v. Mathematica. Dit bestand is ook beschikbaar samen met de broncode.

Bz,ring,α(z) = ∥h∥
h


σmµ0s
2

(T1 + T2 + T3)

T1 =

kz − R1
s

2

p
R²
1 + z

2

T2 =

2hk + R1 − kz
s

2

p
R²
1 + h

2s

2 + 2h(kR1 − z) + z

2

T3 =

k
s

3

log "
kR1 − z + s

p
R²
1 + z

2
hs² + kR1 − z + s

p
2hkR1 + R²
1 + h

2s

2 − 2hz + z

2

h = (R2 − R1) tan(α)

k =

R2 − R1
h

= cot(α)

s =

p
k

2 + 1 = csc(α)

(3)


2

Bz(z) = Bz,ring,α
z +

d + 2∥h∥
2
− Bz,ring,−α
z −

d + 2∥h∥
2
(4)

3

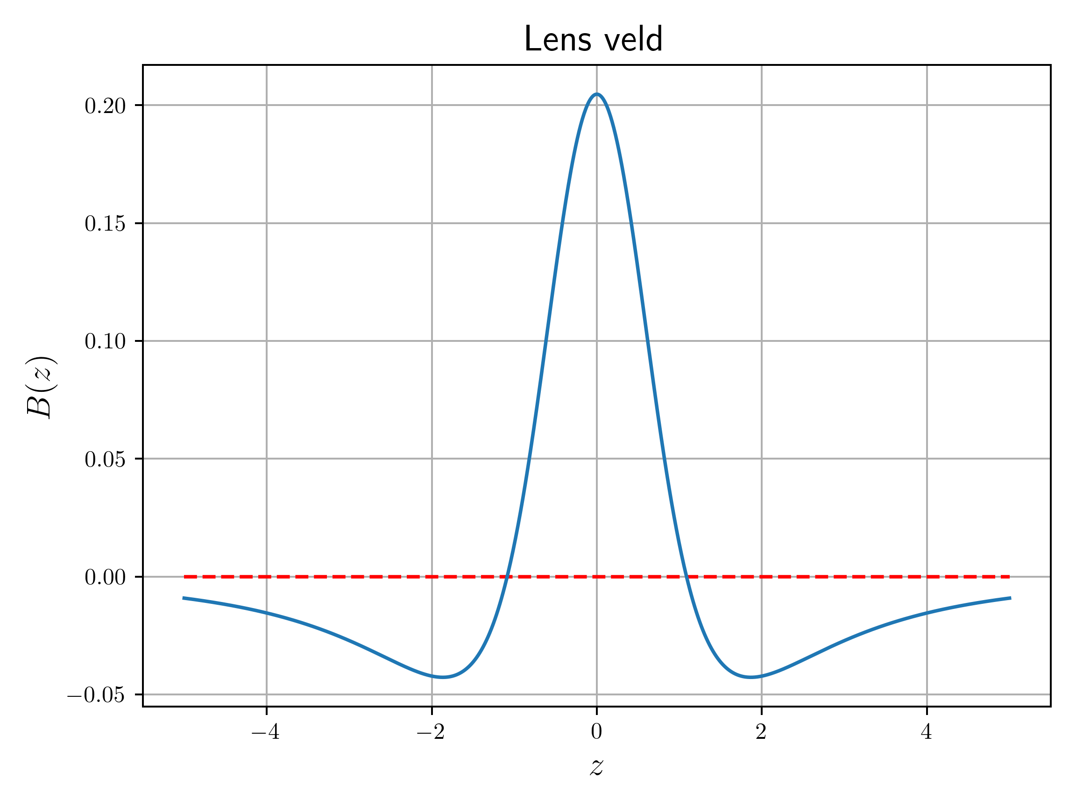
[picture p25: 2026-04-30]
images/B_field.png

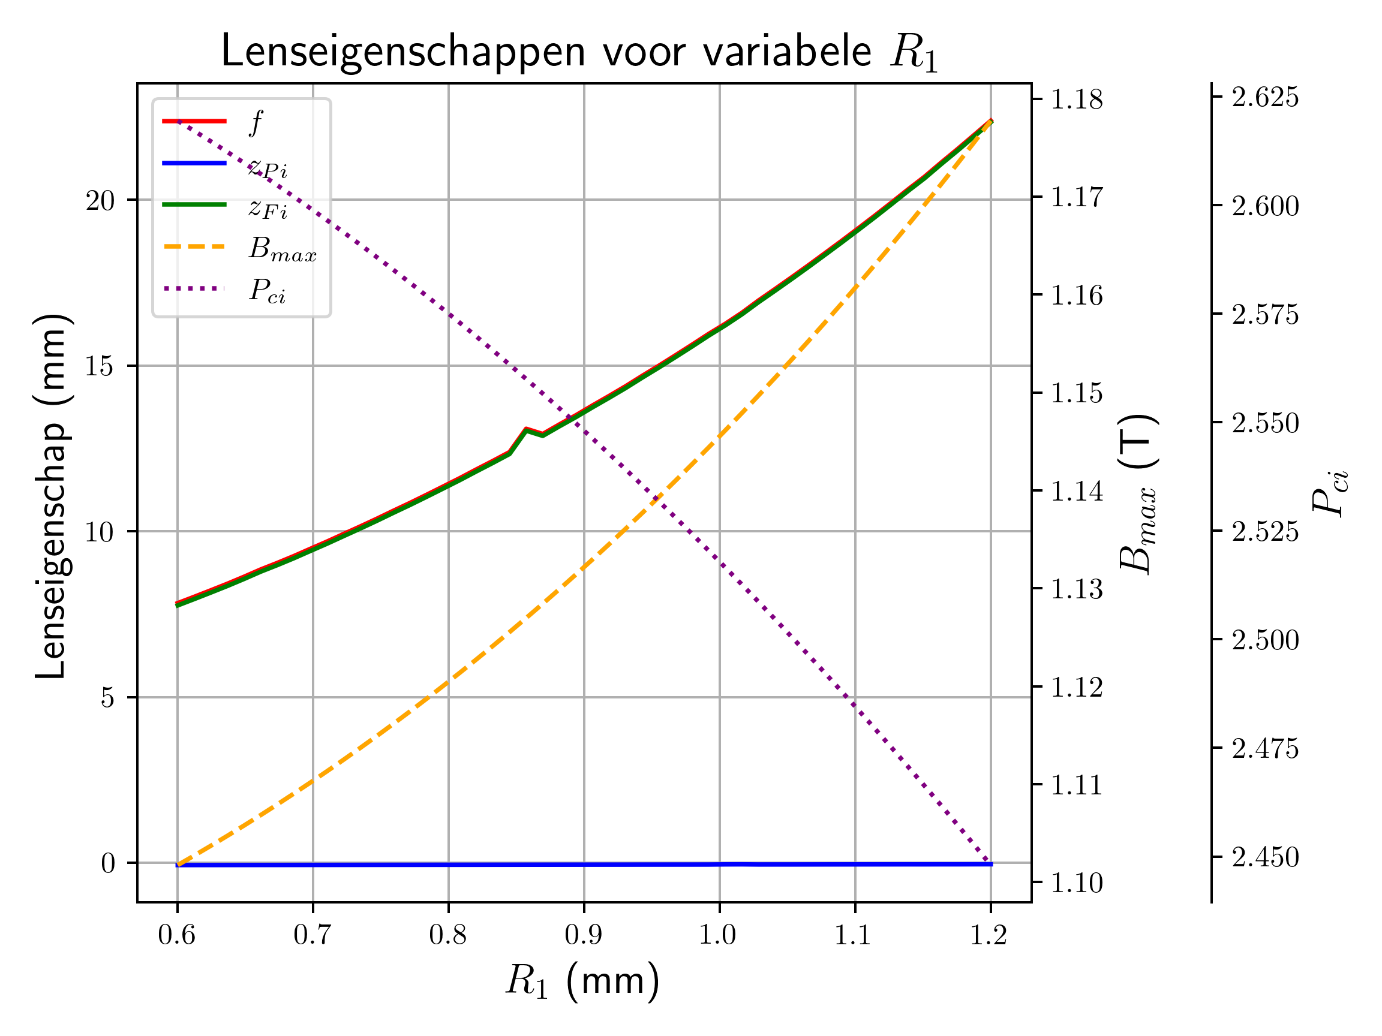
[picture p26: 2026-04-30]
images/variable_R_1.png

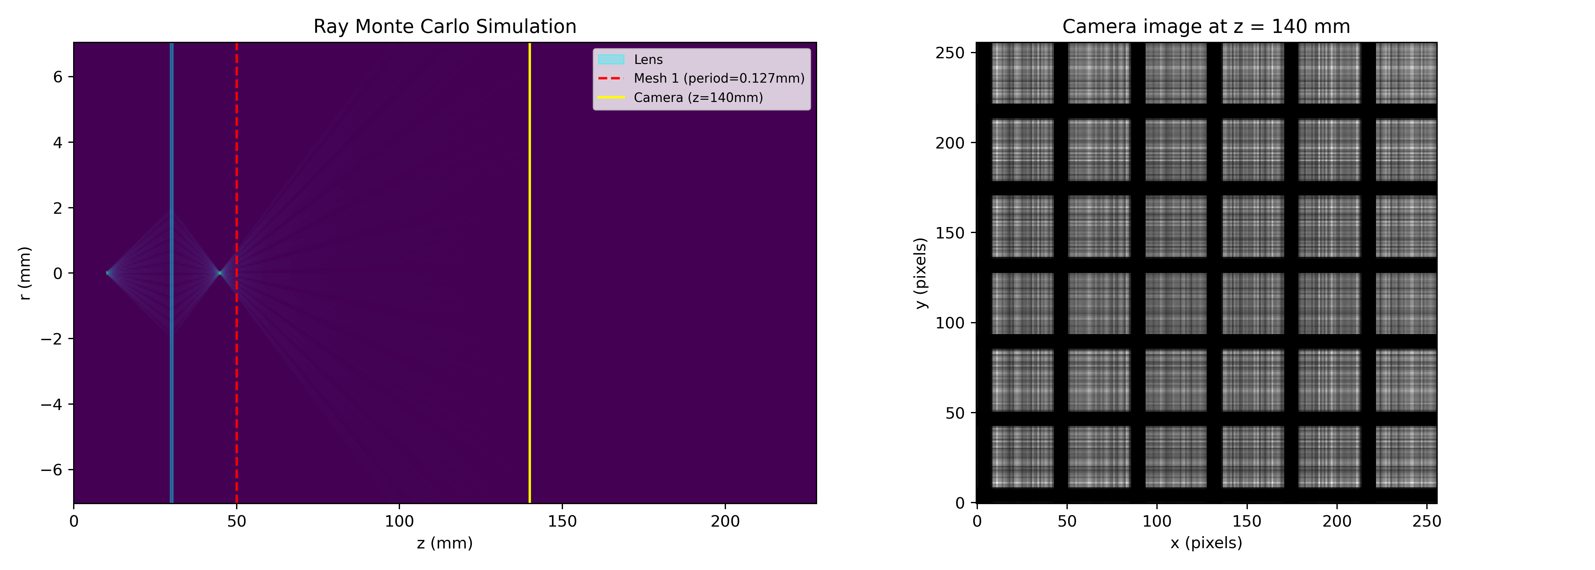
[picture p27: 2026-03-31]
images/200mesh_pointsource_plot.png

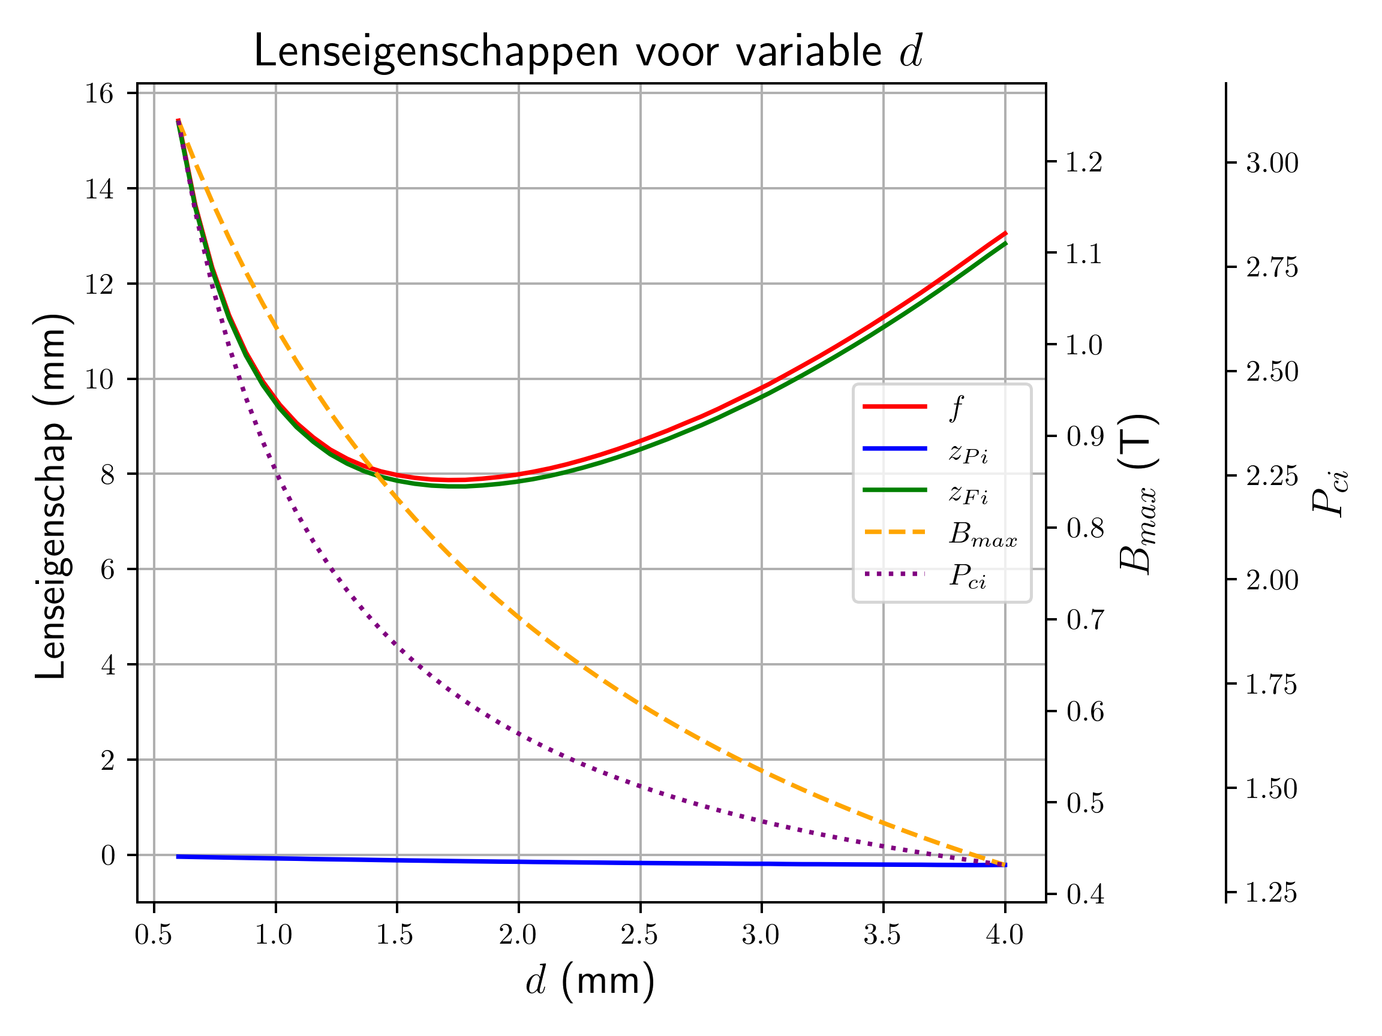
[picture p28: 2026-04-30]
images/variable_d.png

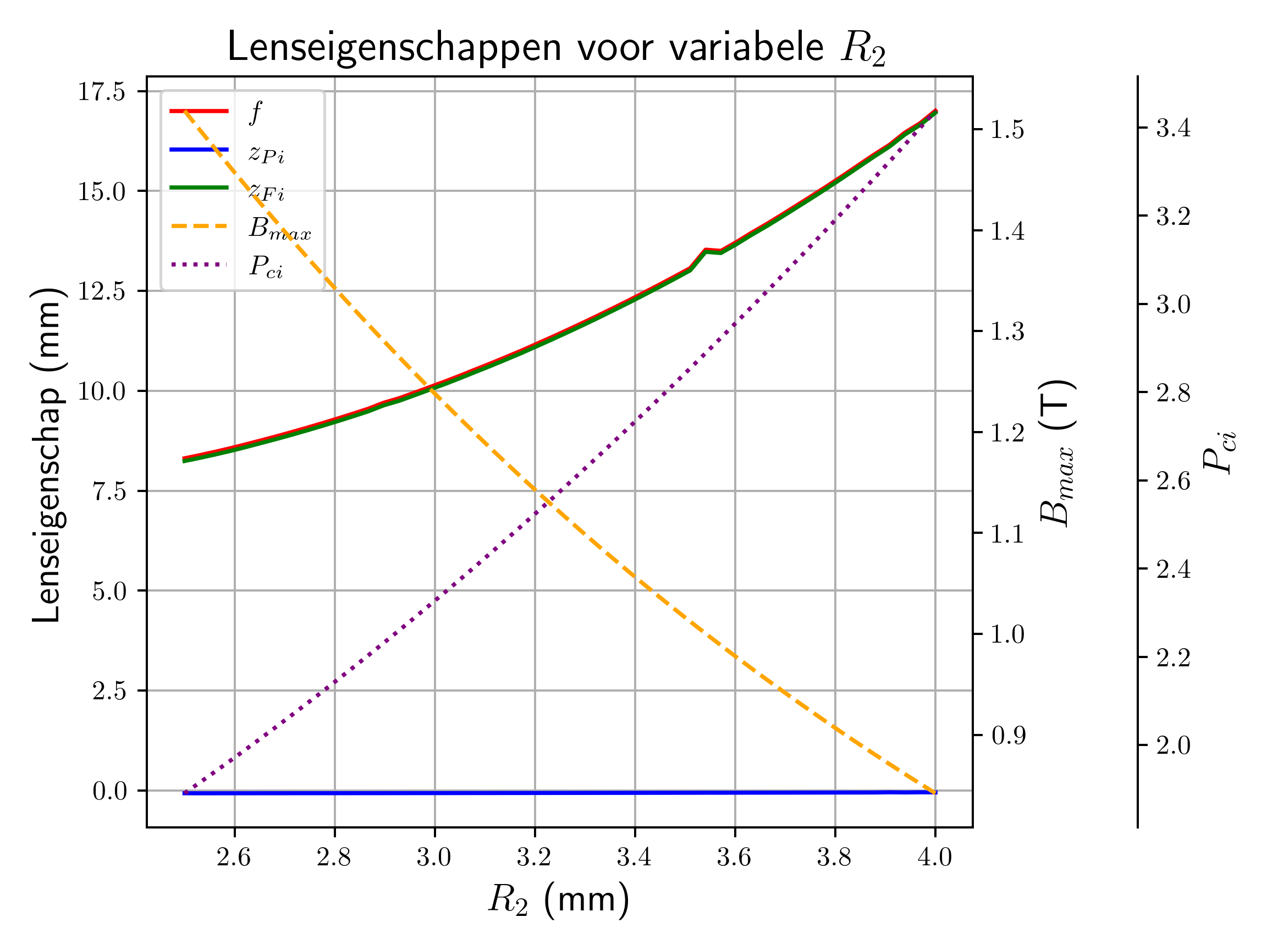
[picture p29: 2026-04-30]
images/variable_R_2.png

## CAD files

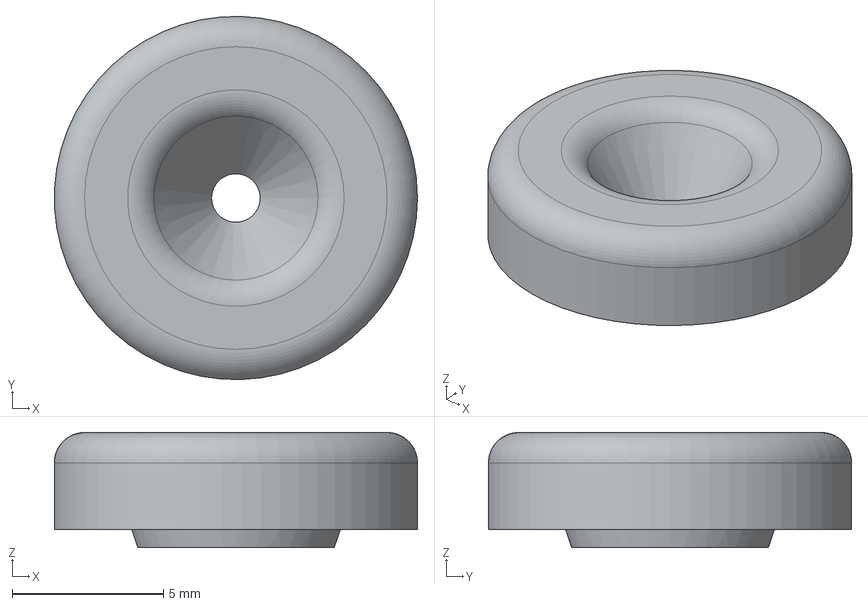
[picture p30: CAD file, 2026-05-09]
3D_models/PermanentMagnetLens.step
12.0 x 12.0 x 3.80 mm

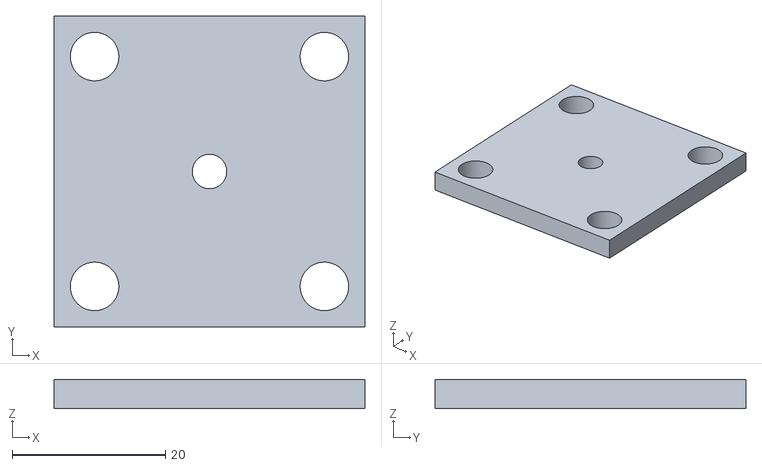
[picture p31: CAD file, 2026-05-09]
3D_models/ThorLabsGrid.stl
40.6 x 40.6 x 3.80

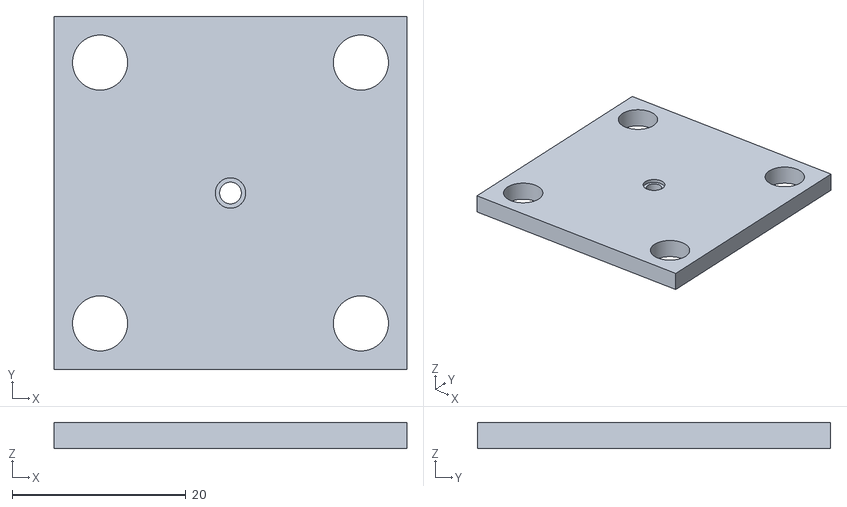
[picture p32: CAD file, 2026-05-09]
3D_models/ThorLabsAperture.stl
40.6 x 40.6 x 3.00

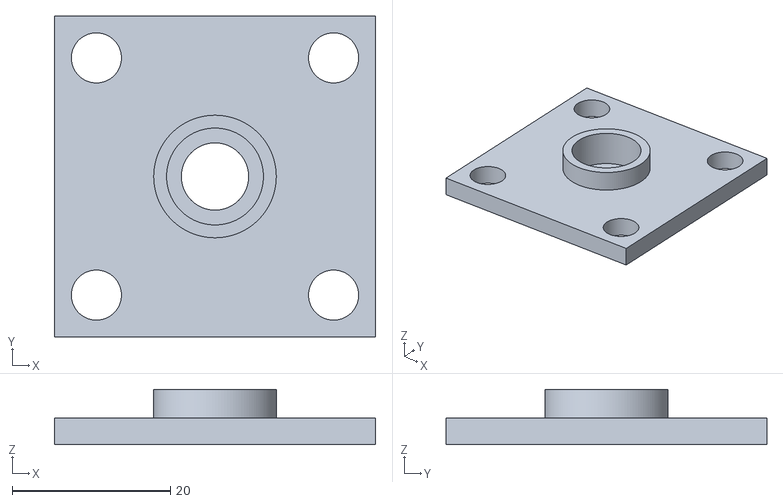
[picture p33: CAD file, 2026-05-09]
3D_models/ThorLabsLens.stl
40.6 x 40.6 x 7.00

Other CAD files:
3D_models/PermanentMagnetLens.FCStd
3D_models/ThorLabsPlates.blend

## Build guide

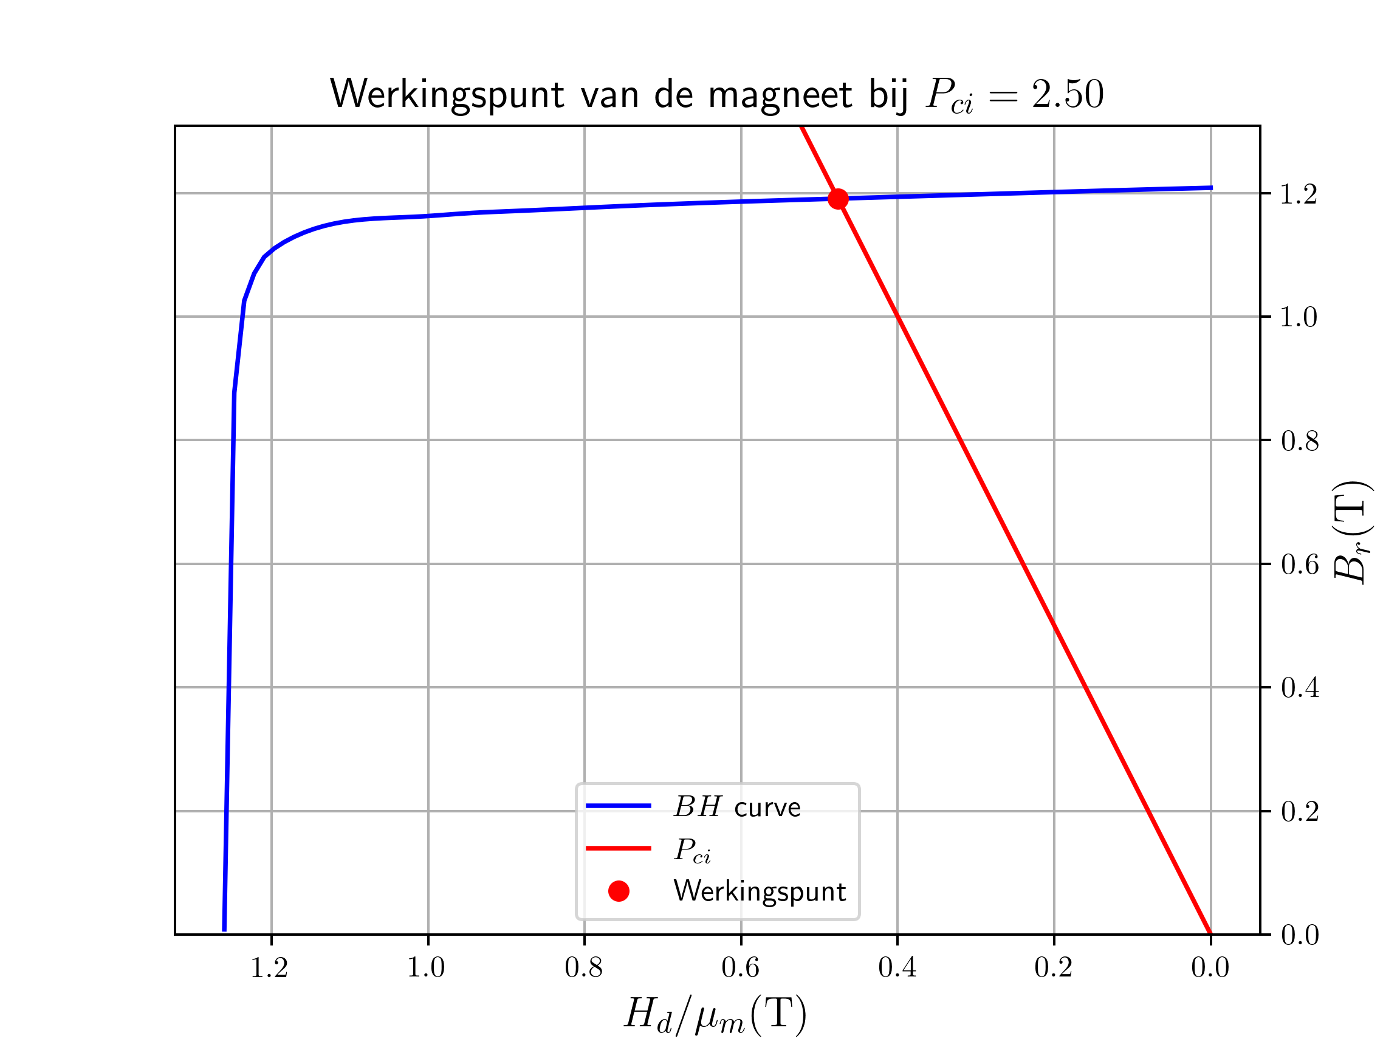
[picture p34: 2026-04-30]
images/operating_point.png

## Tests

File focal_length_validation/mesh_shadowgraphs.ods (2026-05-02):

Option 1: Parralel beam |  |  |  |  |  | Setup |  |  |  |  |  |  | Measurements
 |  |  |  |  |  | 3rd run |  |  | rel | abs |  |  | Lens
lens_to_mesh (mm) | 43,14 |  |  |  |  | Tower |  | Lens position | 0 | 101,08 | 89,58 |  | Thickness | 8,4
mesh_to_detector (mm) | 83,78 |  |  |  |  | Lens plate |  | Mesh position | 43,14 | 144,22
mesh_pitch_size (mm) | 0,254 |  |  |  |  | 4mm spacer |  | Camera position | 126,92 | 228 |  |  | Lens plate
mesh_line_thickness (mm) | 0,05 |  |  |  |  | 9mm spacer |  | Correction term | 0 |  |  |  | Thickness with lens | 9,24
mesh_gap_distance (mm) | 0,204 |  |  |  |  | gap | 24,61 |  |  |  |  |  | Bottom thickness | 0,84
detector_pixelsize (mm) | 0,055 |  |  |  |  | grid plate |  | Total available length | 228,4 |  |  |  | Plate thickness
 |  |  |  |  |  | gap |  | Polepiece to lens | 101,48
measured_gap_distance (pixels) |  |  |  |  |  | detector |  |  |  |  |  |  | Grid plate
measured_gap_distance (mm) | 0,863191852 |  |  |  |  |  |  |  |  |  |  |  | Thickness | 1,63
 |  |  |  |  |  | Full stack length (top of plate) |  |  |  |  |  |  | Inset | 0,49
Magnification | 4,231332607 |  |  |  |  | 121,73 |  |  |  |  |  |  | Bottom thickness | 1,14
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

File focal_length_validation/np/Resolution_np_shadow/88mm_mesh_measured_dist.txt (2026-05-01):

1.6716720730304808
1.6179193983481004
1.6585741199425745
1.4707651468899134

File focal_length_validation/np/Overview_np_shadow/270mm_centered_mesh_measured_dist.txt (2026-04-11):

5.043202044523234
4.867811468199741
4.900240018583568
4.687129472845998
4.632323529218167
4.516524200940073
4.5216777990585735
5.041187397407498
5.0532142017084265
5.014194559117426
5.065016788196271
5.047609349532425
5.1172348364864675

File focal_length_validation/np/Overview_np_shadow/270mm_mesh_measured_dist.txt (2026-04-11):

3.412392788244205
3.380150807654092
3.3386018276893696
3.306665212036879
3.0952265557868848
3.117609935587438
3.18706460513785
3.126100311698028
3.0971029009747837
2.964309646896624
3.478703201479012
3.2422309102242886

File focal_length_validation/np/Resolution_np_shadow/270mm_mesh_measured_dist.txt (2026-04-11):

5.1518521458449635
5.197614678065319
5.2157518839365435
5.244578002622861
5.199929930012288
5.229685057842352
5.237228755011899
5.286781023727913
5.3116492585208315
4.902631364605131
5.049791251803994
5.049791251803994
4.926911837725807
4.773993841398519
4.695477333882489
4.722658770862357
4.655596979313032
5.0680774846365635

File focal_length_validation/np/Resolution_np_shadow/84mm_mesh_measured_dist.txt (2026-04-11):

0.35583536267315985
0.37336309108738147
0.39036385915484934
0.38820038497055975
0.3336330430378407
0.32008169574506423
0.3759233251338818
0.3420693877443035
0.37031166841906904
0.36594793042403856

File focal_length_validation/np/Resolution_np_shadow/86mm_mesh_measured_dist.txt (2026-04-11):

0.4270391376839075
0.40217396555919804
0.40849822590857987
0.40103852880214225
0.3596947729930378
0.3996532447705418
0.4256081778265484
0.380053423000308
0.40157595982753463
0.3953124291426566
0.3781027509774288
0.39832502766213856
0.4506298055383644

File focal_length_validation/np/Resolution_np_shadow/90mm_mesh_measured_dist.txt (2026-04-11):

1.708606480444519
1.6496655104092135
1.7441145994737965
1.7119863990468742
1.68359970834035
1.7225312486057924

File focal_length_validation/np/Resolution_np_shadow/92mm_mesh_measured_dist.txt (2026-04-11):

1.8046915104802004
1.8472259097402688
1.8120245585657284
1.8054497962481633
1.8054497962481653
1.8040715994337793
1.7762499754710455
1.7828333576655093

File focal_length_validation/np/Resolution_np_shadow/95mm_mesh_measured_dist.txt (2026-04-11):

1.988145532699462
2.0136572568442577
1.9873512893211864
1.9748664407385503
1.9842153402280656
1.9796571750969518
1.857116102815775
1.8495441183629542
1.9098764514115927
1.9266112228963743

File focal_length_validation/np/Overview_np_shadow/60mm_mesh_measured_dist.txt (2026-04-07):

Dist: 0.0009344803727794683 m
Dist: 0.0008807344631454277 m
Dist: 0.0009011075011005543 m
Dist: 0.0009592408709416525 m
Dist: 0.0009217140187914802 m
Dist: 0.0009870882713569483 m
Dist: 0.0009529126597765193 m
Dist: 0.0009585836314873465 m
Dist: 0.0009142995445688912 m
Dist: 0.0008641194282014149 m
Dist: 0.0009819671562812052 m
Dist: 0.0009453428901551211 m
Dist: 0.0008385046968483952 m
Dist: 0.0009748816988697934 m
Dist: 0.0011253977897137696 m
Dist: 0.0008734050614072837 m
Dist: 0.0010467093496581308 m
Dist: 0.0008464343494263403 m
Dist: 0.0008845901492730951 m
Dist: 0.0008641194282014172 m
Dist: 0.0008736936472606613 m
Dist: 0.0008845901492730921 m
Dist: 0.0008790153961913476 m
Dist: 0.0008344360904334673 m
Dist: 0.0008736936472606603 m
Dist: 0.001285388650758454 m
Dist: 0.0009539702768165527 m
Dist: 0.0012177096636649734 m
Dist: 0.0009612098929334797 m
Dist: 0.0008875774365623577 m
Dist: 0.0008473273699132512 m
Dist: 0.0007673926967533226 m
Dist: 0.0007319151043723125 m
Dist: 0.0010302017669278256 m
Dist: 0.0009759155079607781 m
Dist: 0.0011005960213373233 m
Dist: 0.0009690459728136596 m
Dist: 0.0009527803751004086 m
Dist: 0.000799095780398026 m
Dist: 0.0009377120148378816 m
Dist: 0.0009673535422015296 m
Dist: 0.0008942271094253745 m
Dist: 0.0007902131377294994 m
Dist: 0.0009819671562812048 m
Dist: 0.0013639844631962274 m
Dist: 0.0013809746569831251 m
Dist: 0.0011150459803932293 m
Dist: 0.003295692588518437 m
Dist: 0.0008593689195955357 m
Dist: 0.0008535548234216055 m
Dist: 0.0008619174484162646 m
Dist: 0.0009380923198162571 m
Dist: 0.0008862311878868722 m
Dist: 0.0009021749164368415 m
Dist: 0.0008197574987003909 m
Dist: 0.0008308549772676286 m
Dist: 0.0008265629727846502 m
Dist: 0.0007921381150718217 m
Dist: 0.0010435138954417171 m
Dist: 0.0009296816124475273 m
Dist: 0.0008609884538704661 m
Dist: 0.0008913336166132842 m
Dist: 0.0009982500397314694 m
Dist: 0.0010399573081727096 m
Dist: 0.001025520927654601 m
Dist: 0.0010180949840156005 m
Dist: 0.0010163466799482494 m
Dist: 0.0009953955121490392 m
Dist: 0.0010501958955425768 m
Dist: 0.0010023687516396889 m
Dist: 0.0008265629727846487 m

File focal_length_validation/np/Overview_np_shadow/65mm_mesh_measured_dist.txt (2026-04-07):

Dist: 0.0008853980096866979 m
Dist: 0.0008681978157697932 m
Dist: 0.0009506401063225427 m
Dist: 0.000966225409034015 m
Dist: 0.0008827010463482824 m
Dist: 0.000861321616685067 m
Dist: 0.0008445835596074759 m
Dist: 0.0008535154720125543 m
Dist: 0.0008610547677539657 m
Dist: 0.0008949499229293765 m
Dist: 0.000885138419265612 m
Dist: 0.0008788852474178288 m
Dist: 0.0008958161434156775 m
Dist: 0.0009262127647626927 m
Dist: 0.000861955051800661 m
Dist: 0.0008414827844521136 m
Dist: 0.001020447765422037 m
Dist: 0.0009525419016184543 m
Dist: 0.0009953673036972692 m
Dist: 0.0011119183689925522 m
Dist: 0.000966076747534707 m
Dist: 0.000932333384291014 m
Dist: 0.0009641420621272483 m
Dist: 0.0009084574411053326 m
Dist: 0.0010221353869147504 m
Dist: 0.0009540786736339731 m
Dist: 0.001006959081231744 m
Dist: 0.001012052598027175 m
Dist: 0.0012056482349708092 m
Dist: 0.0010569825176096792 m
Dist: 0.001282874648126439 m
Dist: 0.0010177260031121933 m
Dist: 0.001448811756840459 m

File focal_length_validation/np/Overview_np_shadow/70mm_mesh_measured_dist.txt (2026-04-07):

Dist: 0.0009173675656160002 m
Dist: 0.0008628123907635228 m
Dist: 0.0008624279544288946 m
Dist: 0.0009104732802371127 m
Dist: 0.0007621110068798236 m
Dist: 0.0007798082996254415 m
Dist: 0.0008763235972842587 m
Dist: 0.0009446421932688212 m
Dist: 0.0007975286995442387 m
Dist: 0.0008513707284752474 m
Dist: 0.0007207049623482185 m
Dist: 0.0007847741244892398 m
Dist: 0.0007375335317907141 m
Dist: 0.0008154450085643552 m
Dist: 0.0008015578449185941 m
Dist: 0.0007451381595280617 m
Dist: 0.0008588499707840304 m
Dist: 0.000880368811570299 m
Dist: 0.0008735079185362204 m
Dist: 0.0009073459297549914 m
Dist: 0.0009058305065783223 m
Dist: 0.0009953860518623961 m
Dist: 0.0009449931843026098 m
Dist: 0.0009144192367566345 m
Dist: 0.0010759400090928875 m
Dist: 0.0010491888892563636 m
Dist: 0.0009346595704429265 m
Dist: 0.0012450295132129996 m
Dist: 0.0008029750692665707 m
Dist: 0.0011301837304148058 m
Dist: 0.0010583153747839415 m
Dist: 0.000722674284615649 m
Dist: 0.000831666918646876 m
Dist: 0.000831496010623293 m
Dist: 0.0008522605857638545 m
Dist: 0.001022108478529671 m
Dist: 0.001035737193312387 m
Dist: 0.0009357740096523889 m
Dist: 0.0008857871772158617 m
Dist: 0.0008774041446704104 m
Dist: 0.0008499784614300428 m
Dist: 0.0010840114269234724 m
Dist: 0.0011461257544474524 m
Dist: 0.0009672406900316271 m
Dist: 0.0012842880328716333 m

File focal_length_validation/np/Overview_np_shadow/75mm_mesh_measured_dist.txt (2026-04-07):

Dist: 0.000984230861845919 m
Dist: 0.0008405872542743128 m
Dist: 0.000899610153699187 m
Dist: 0.0007861126457785316 m
Dist: 0.0008043276702610743 m
Dist: 0.0008345760465534326 m
Dist: 0.000869486163823519 m
Dist: 0.0008885205445601219 m
Dist: 0.0008970233272370577 m
Dist: 0.0011248914840568639 m
Dist: 0.0012619708454249042 m
Dist: 0.0009921477908129957 m
Dist: 0.0008809033879574085 m
Dist: 0.0008244912934460384 m
Dist: 0.0007833488057205247 m
Dist: 0.000753511272852376 m
Dist: 0.0007142473369417084 m
Dist: 0.0008244912934460392 m
Dist: 0.0008127582049042776 m
Dist: 0.0008816065637931515 m
Dist: 0.0008634967260567848 m
Dist: 0.0006774001547709598 m
Dist: 0.0008071156428156992 m
Dist: 0.0007336141027929871 m
Dist: 0.0008090327848107393 m
Dist: 0.0006550774487675713 m
Dist: 0.0008290819855233466 m
Dist: 0.0009615395928474539 m
Dist: 0.0008858138968051582 m
Dist: 0.0009301743365168222 m
Dist: 0.0009632298240477786 m
Dist: 0.000859810970253404 m
Dist: 0.0008941691745263249 m
Dist: 0.0008784378398530479 m
Dist: 0.0008583683333810961 m
Dist: 0.0010794920020227605 m
Dist: 0.0009712381911967953 m
Dist: 0.0012601281028812956 m
Dist: 0.0008464642740925681 m
Dist: 0.0009986067998975 m
Dist: 0.0010174334226653802 m
Dist: 0.0008763189917265861 m
Dist: 0.0011622806481561758 m
Dist: 0.0009519862977429874 m
Dist: 0.0009446349421849164 m
Dist: 0.0009017601738625981 m
Dist: 0.0009184419383764868 m
Dist: 0.0011197150991772737 m
Dist: 0.0012644849172865325 m
Dist: 0.0011188154237460443 m
Dist: 0.0007681716069118451 m
Dist: 0.0008460981563098299 m
Dist: 0.0008071156428157 m
Dist: 0.0007347746349243502 m
Dist: 0.0008667200763500657 m
Dist: 0.00077469824592108 m
Dist: 0.000742639018437824 m
Dist: 0.0007697832983912965 m
Dist: 0.0007456576771122849 m

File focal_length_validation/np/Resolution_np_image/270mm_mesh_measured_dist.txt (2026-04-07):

Dist: 0.0009776166036486315 m
Dist: 0.0012052463900223927 m
Dist: 0.0008910625049293384 m
Dist: 0.0011107829389976178 m
Dist: 0.0008796852271843778 m
Dist: 0.001098924143890857 m
Dist: 0.000852162447540647 m
Dist: 0.0009841279531113182 m
Dist: 0.0009069714770084842 m
Dist: 0.0010193442515730705 m
Dist: 0.0009363642013395463 m
Dist: 0.0010045897041926054 m
Dist: 0.0009510504323044788 m
Dist: 0.001129533881000769 m
Dist: 0.0009981570933113415 m
Dist: 0.0011422630954512256 m

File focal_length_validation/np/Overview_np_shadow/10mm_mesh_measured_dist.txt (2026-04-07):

Dist: 0.0009709829544704789 m
Dist: 0.0010791033123662107 m
Dist: 0.0008881892128434398 m
Dist: 0.001073669150360163 m
Dist: 0.000998185743864021 m
Dist: 0.0012711940272822132 m
Dist: 0.0009599020423375368 m
Dist: 0.0011849597354316934 m
Dist: 0.001072019171737947 m
Dist: 0.0009808409021751778 m
Dist: 0.001038098583105407 m
Dist: 0.0009377577704328468 m
Dist: 0.0008211929004114905 m
Dist: 0.0008524630423114529 m
Dist: 0.0007812322359842512 m
Dist: 0.0008214740185461861 m
Dist: 0.0007673160442297867 m
Dist: 0.0012126303909438115 m
Dist: 0.0007917032798261319 m
Dist: 0.0010593081743491906 m
Dist: 0.0008259588963800404 m
Dist: 0.0009325728836629097 m
Dist: 0.0011253968648703523 m
Dist: 0.0009854595967178975 m
Dist: 0.0010324486204750505 m
Dist: 0.001027966188508741 m
Dist: 0.001032970303862247 m
Dist: 0.0010760320917598688 m
Dist: 0.0009340572167187861 m
Dist: 0.0012517927976381093 m
Dist: 0.0008685621717055349 m
Dist: 0.0008985273597496853 m
Dist: 0.000977303496093757 m
Dist: 0.000942015861145843 m
Dist: 0.0008934593862258964 m
Dist: 0.0010404683361291674 m
Dist: 0.0009725669407672843 m
Dist: 0.0010021871211986937 m
Dist: 0.0010128055059511539 m
Dist: 0.0009514460099119615 m
Dist: 0.0009939359884570157 m
Dist: 0.0010294625010744234 m
Dist: 0.001059308174349191 m
Dist: 0.0008811423973379836 m
Dist: 0.0012851636118611778 m
Dist: 0.001134184637635274 m
Dist: 0.0007713177195779164 m
Dist: 0.0007591480476873558 m
Dist: 0.0008226910871081621 m
Dist: 0.0008095830147790648 m
Dist: 0.0007312627755404464 m

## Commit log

2026-03-31 excel to calculate f
    [mesh_shadowgraphs.xlsx]
2026-04-02 lab session 01/04/2026
    [mesh_shadowgraphs.ods]
2026-04-07 image processing
    [mesh_shadowgraphs.ods]
2026-04-11 Add report tex file
    [mesh_shadowgraphs.ods]
2026-04-15 add demag feature and fix Br value
    [NdFeB_BH_curve.csv]
2026-05-06 clean up
    [mesh_shadowgraphs.ods, mesh_shadowgraphs.xlsx]
2026-05-09 add 3D models
    [PermanentMagnetLens.FCStd, PermanentMagnetLens.step, ThorLabsAperture.stl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]
